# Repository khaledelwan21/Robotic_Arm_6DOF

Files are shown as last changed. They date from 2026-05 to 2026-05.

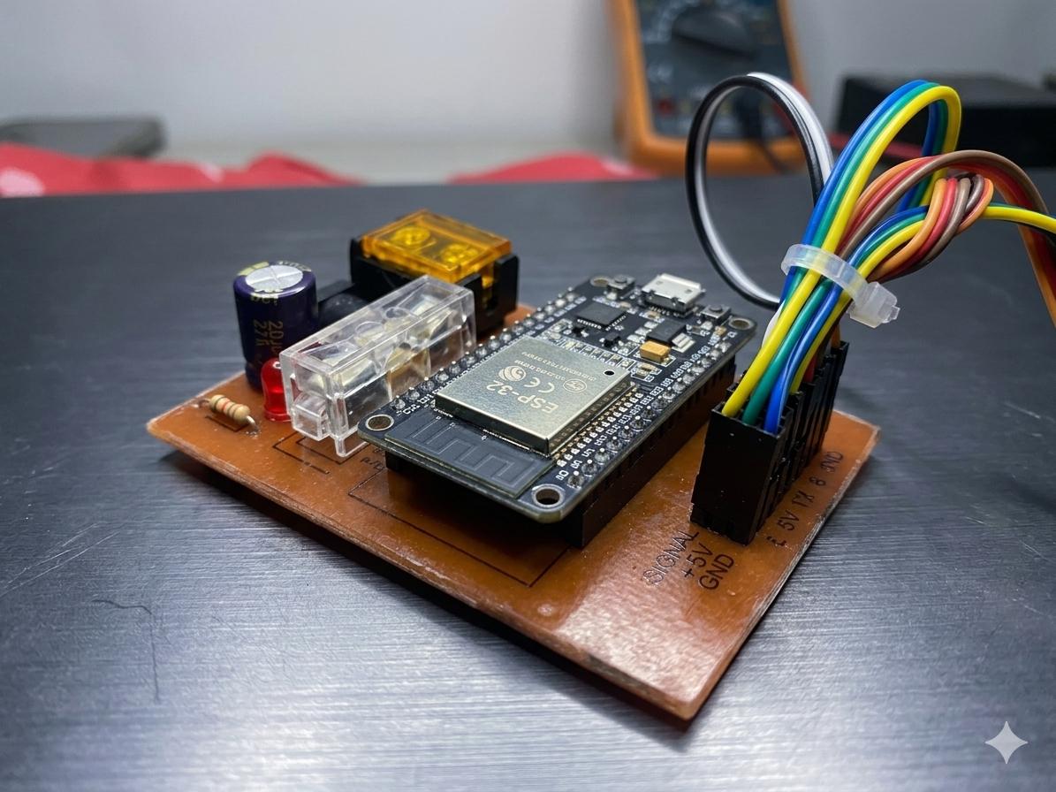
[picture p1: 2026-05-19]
PCB/PCB_VIEW.jpeg

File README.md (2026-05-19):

# 🦾 6-DOF Robotic Arm — Full Pipeline

> Trajectory Planning · Inverse Kinematics · ROS2 MoveIt2 · Real-Time Simulation · ESP32 Hardware Control







---

## 📌 Project Overview

A complete end-to-end 6 Degrees-of-Freedom robotic arm project developed at **Alexandria University, Faculty of Engineering**.

This repository covers the full development pipeline — from mechanical CAD design to physics simulation, trajectory planning, motion planning in ROS2, custom PCB hardware, and real-time teleoperation via PlayStation controller.

**Team:**
- Khaled Ahmed Elwan — ID: 8782
- Taha Ahmed Elaghoury — ID: 8745
- Marwan Mahmoud Ali Bakhit — ID: 9023

**Supervisor:** Dr. Sohair Rezeka

---

## 🗂️ Repository Structure

```
robotic-arm-6dof/
├── Matlab/                        # MATLAB Simscape simulation & trajectory planning
│   ├── ArmFK.slx                  # Main Simscape Multibody model
│   ├── myRoobot.m                 # Rigid body tree definition
│   ├── Arm_DataFile.m             # Link/joint data
│   ├── trajPlot.m                 # Trajectory visualization
│   └── FK_Plot.m                  # Forward kinematics plots
│
├── src/                           # ROS2 workspace packages
│   ├── robot_arm_description/     # URDF + STL meshes
│   ├── robot_arm_moveit_config/   # MoveIt2 configuration
│   └── robot_arm_control/         # Python trajectory scripts (MoveItPy)
│
├── pcb/                           # Custom PCB design (KiCad)
│
├── docs/
│   └── report.pdf                 # Full technical report
│
└── README.md
```

---

## 🔧 System Specifications

| Parameter | Value |
|---|---|
| Degrees of Freedom | 6 DOF |
| Joint Configuration | All Revolute |
| Joint Names | Shoulder · Elbow · Wrist · Rolling · Pitch · Gripper |
| Microcontroller | ESP32-WROOM DevKitC |
| Servo Motors | 5× MG996R + 1× SG90 |
| Simulation Engine | MATLAB Simscape Multibody |
| Motion Planner | OMPL RRTConnect (via MoveIt2) |
| IK Solver | KDL Kinematics Plugin |
| ROS Version | ROS2 Jazzy Jalisco |
| CAD Tool | SolidWorks 2023 |
| PCB Tool | KiCad |

---

## 📐 DH Parameters

| Joint | Link | a (mm) | d (mm) | α (°) | θ |
|---|---|---|---|---|---|
| 1 | Shoulder | 0 | 57 | 90 | θ1 |
| 2 | Elbow | 37.5 | 0 | 0 | θ2 |
| 3 | Wrist | 120 | 0 | 0 | θ3 |
| 4 | Rolling | 99.7 | 14.5 | 90 | θ4 |
| 5 | Pitch | 22.7 | 0 | -90 | θ5 |
| 6 | Gripper Base | 37.8 | 14.5 | 0 | θ6 |

---

## 🚀 Pipeline Overview

```
SolidWorks CAD
      ↓
MATLAB Simscape Multibody
      ↓  (Physics simulation + DH parameters)
Polynomial Trajectory Planner (5th-order)
      ↓  (Smooth waypoint interpolation)
IK Solver (MATLAB Robotics Toolbox)
      ↓  (Joint angles from Cartesian poses)
ESP32 Hardware Control (50Hz streaming via MATLAB)
      ↓
──────────────────────────────
SW2URDF Export (SolidWorks)
      ↓
ROS2 Jazzy + MoveIt2
      ↓  (OMPL RRTConnect + KDL IK)
RViz2 Real-Time Simulation
      ↓
PS Controller Teleoperation (Bluetooth)
```

---

## 1️⃣ MATLAB Simscape Simulation

### Features
- **5th-order Polynomial Trajectory** interpolation between Cartesian waypoints
- **IK Solver** maps end-effector poses → joint angles in real time
- **Forward Kinematics** verification confirms sub-mm accuracy
- **3D Trajectory Animation** — star shape, heart shape, custom paths
- **Workspace Analysis** — full reachable volume (~300mm radius sphere)

### Joint Limits

| Joint | Min | Max |
|---|-----|-----|
| Shoulder | -90° | +90° |
| Elbow | -90° | +90° |
| Wrist | -90° | +90° |
| Rolling | -90° | +90° |
| Pitch | -90° | +90° |
| Gripper | -90° | +90° |

### Run the Simulation

```matlab
% Open MATLAB R2024a
open('Matlab/ArmFK.slx')

% Run simulation
sim('ArmFK')

% Plot trajectory
run('Matlab/trajPlot.m')
```

---

## 2️⃣ ROS2 + MoveIt2 Setup

### Prerequisites

```bash
# Install ROS2 Jazzy
sudo apt install ros-jazzy-moveit
sudo apt install ros-jazzy-joint-state-publisher-gui
sudo apt install ros-jazzy-xacro
sudo apt install liburdfdom-tools
```

### Build

```bash
cd ros2_arm_ws
colcon build
source install/setup.bash
```

### Run

```bash
# Terminal 1 — Launch MoveIt2 + RViz2
ros2 launch robot_arm_moveit_config demo.launch.py

# Terminal 2 — Python trajectory control
ros2 launch robot_arm_control trajectory_planning.launch.py
```

### MoveIt2 Configuration
- **Planning Group:** `arm` (shoulder → elbow → wrist → rolling → pitch → follower-gear)
- **IK Solver:** KDL (`kdl_kinematics_plugin/KDLKinematicsPlugin`)
- **Motion Planner:** OMPL RRTConnect
- **Planning Time:** 5.0s | **Velocity Scaling:** 10%

---

## 3️⃣ PS Controller Teleoperation

Real-time Bluetooth teleoperation of the simulated arm via PlayStation controller:

```bash
# Install joy package
sudo apt install ros-jazzy-joy

# Connect PS controller via Bluetooth, then:
# Terminal 1 — Start MoveIt
ros2 launch robot_arm_moveit_config demo.launch.py

# Terminal 2 — Start joy node
ros2 run joy joy_node

# Terminal 3 — Start teleoperation
ros2 run robot_arm_control ps_teleop.py
```

---

## 4️⃣ ESP32 Hardware Control

### Angle Mapping Formula

```
servo_position = (joint_angle_deg + 90) / 180
```

| Joint Angle | Servo Position | Servo Angle |
|---|---|---|
| -90° | 0.0 | 0° |
| 0° | 0.5 | 90° |
| +90° | 1.0 | 180° |

### Pin Mapping

| Servo | ESP32 Pin | Joint |
|---|---|---|
| SERVO1 | D13 | Shoulder |
| SERVO2 | D12 | Elbow |
| SERVO3 | D14 | Wrist |
| SERVO4 | D27 | Rolling |
| SERVO5 | D26 | Pitch |
| SERVO6 | D25 | Gripper |

### Streaming from MATLAB

```matlab
% Connect to ESP32
a = arduino('COM9', 'ESP32');

% Stream joint angles at 50Hz
for i = 1:length(joint_angles)
    servo_pos = (joint_angles(i, :) + 90) / 180;
    writePosition(servo1, servo_pos(1));
    writePosition(servo2, servo_pos(2));
    % ... remaining joints
    pause(0.02); % 50Hz
end
```

---

## 5️⃣ Custom PCB

Designed in KiCad — clean ESP32 ↔ servo interface:

- 6-channel servo header connectors (SIGNAL · +5V · GND)
- 220µF electrolytic capacitor for servo power filtering
- Fuse protection on servo power rail
- Power jack for external 5V supply
- LED power indicator with 220Ω current-limiting resistor

---

## ✅ Results

| Objective | Status |
|---|---|
| SolidWorks 3D mechanical design | ✅ Complete |
| Simscape Multibody physics simulation | ✅ Complete |
| Polynomial trajectory planning | ✅ Complete |
| IK solver integration | ✅ Complete |
| 3D end-effector animation | ✅ Complete |
| Robot workspace visualization | ✅ Complete |
| ROS2 Jazzy URDF model | ✅ Complete |
| MoveIt2 real-time motion planning | ✅ Complete |
| PS controller teleoperation | ✅ Complete |
| Custom PCB design | ✅ Complete |
| ESP32 servo hardware control | ✅ Complete |

---

## 🔮 Future Work

- [ ] TRAC-IK upgrade for better singularity handling
- [ ] Gazebo physics simulation
- [ ] Camera integration for visual feedback
- [ ] Full hardware loop: PS Controller → ROS2 → ESP32 → Real Servos
- [ ] Pick & Place demo task

---

## 📚 References

1. MATLAB Robotics System Toolbox Documentation, MathWorks, R2024a
2. Simscape Multibody User Guide, MathWorks, R2024a
3. MoveIt2 Documentation — https://moveit.ros.org
4. ROS2 Jazzy Documentation — https://docs.ros.org/en/jazzy
5. Craig, J.J., *Introduction to Robotics: Mechanics and Control*, 3rd ed., Pearson, 2005
6. ESP32 Technical Reference Manual, Espressif Systems, 2024

**Faculty of Engineering — Alexandria University — 2025/2026**

---

<p align="center">
  <i>Built with ❤️ at Alexandria University</i>
</p>

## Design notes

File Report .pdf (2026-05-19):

## Faculty of Engineering Alexandria University

# 6-DOF Robotic Arm

## Trajectory Planning | Simulation | Hardware Control

## Submitted by:

Khaled Ahmed Elwan - ID: 8782 Taha Ahmed Elaghoury - ID: 8745 Marwan Mahmoud Ali Bakhit - ID: 9023

## Supervised by:

Dr. Sohair Rezeka

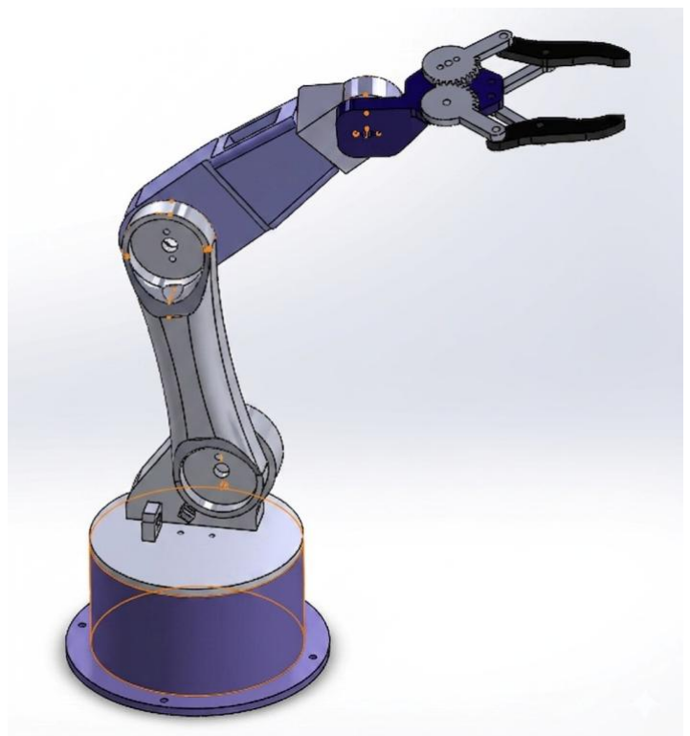
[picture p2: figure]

## 1. Introduction

This report presents the complete design, simulation, trajectory planning, and hardware implementation of a 6 Degrees-of-Freedom (6-DOF) robotic arm. The project integrates a multi-tool engineering workflow that covers the full development cycle, from mechanical CAD modeling and physics-based simulation to motion planning, custom electronics, and real-time servo actuation.

The project was developed by Khaled Ahmed Elwan (ID: 8782), Taha Ahmed Elaghoury (ID: 8745), and Marwan Mahmoud Ali Bakhit (ID: 9023), under the supervision of Dr. Sohair Rezeka at the Faculty of Engineering, Alexandria University.

The completed project stages are summarized as follows:

- Mechanical design of the complete robotic arm using SolidWorks
- Physics-based simulation using MATLAB Simscape Multibody
- Polynomial trajectory planning with six configurable Cartesian waypoints
- Inverse Kinematics (IK) solution using the MATLAB Robotics System Toolbox
- 3D end-effector path animation in MATLAB
- Robot workspace visualization and analysis
- Real-time motion planning and simulation using ROS2 Jazzy and MoveIt2 in RViz2
- Custom PCB design for servo motor interfacing and power distribution
- Hardware servo control using an ESP32-WROOM microcontroller

## 2. System Overview

The robotic arm was developed as a serial manipulator with revolute joints. The prototype includes five primary arm joints and an actuated gripper, providing the controlled motion required for positioning, orientation adjustment, and object handling. The system combines mechanical design, simulation, motion planning, and embedded control into a single integrated platform.

Parameter | Description
Degrees of Freedom | 6 DOF
Joint Configuration | Revolute joints
Joint Names | Shoulder, Elbow, Wrist, Rolling, Pitch, Gripper
Microcontroller | ESP32-WROOM DevKitC
Number of Servos | 5 active servos + 1 gripper servo
Servo Signal Pins | D13, D12, D14, D27, D26, D25
Control Software | MATLAB R2024a
Simulation Engine | Simscape Multibody
Motion Planner | Polynomial trajectory generation + IK solver
ROS Version | ROS2 Jazzy
Motion Planning Framework | MoveIt2
PCB Design Tool | KiCad
CAD Tool | SolidWorks

## 3. Mechanical Design (SolidWorks)

The complete robotic arm was designed from scratch using SolidWorks. Each component, including the links, joint housings, base, wrist elements, and gripper end-effector, was modeled individually and assembled with the required mechanical constraints to represent the intended joint motion.

The mechanical design workflow included the following steps:

- Individual part modeling for each link, joint housing, and gripper component
- Full assembly of the robotic arm with revolute joint constraints
- Definition of coordinate systems at the relevant joint and end-effector locations
- Gripper end-effector design for object grasping
- Export of the mechanical model for MATLAB Simscape Multibody simulation
- Export of the robot model for ROS2 and MoveIt2 integration
Figures 1 and 2 show the final SolidWorks assembly and the rendered CAD model of the complete robotic arm.

## 3.1 SolidWorks Modeling

In SolidWorks, the robotic arm assembly was constructed and adjusted to ensure accurate part positioning, joint alignment, and link connectivity. Coordinate systems were assigned to the individual components at the joint locations to define the relative motion between consecutive links and to support the subsequent export to Simscape Multibody.

Special attention was given to the end-effector coordinate system. This frame was placed within the end-effector sub-assembly rather than directly on individual gripper parts because assigning the frame to certain parts produced errors during the Simscape export process. Defining the frame at the sub-assembly level provided a more stable reference for the end-effector and improved the reliability of the exported model.

The mechanical assembly includes five main revolute joints responsible for the arm motion, in addition to the joints associated with the gripper mechanism. Each joint was designed to rotate about a defined axis. The base joint provides horizontal rotation of the arm, the shoulder and elbow joints provide vertical lifting and extension, the wrist joints provide end-effector orientation control, and the gripper enables object grasping and holding.

## 3.2 Fabrication

The robotic arm components were fabricated using fused-filament fabrication (FFF) on a Bambu P1S 3D printer. PLA was selected as the structural material, and a 50% infill density was applied to the printed parts.

PLA was selected because it offers high stiffness, low printing shrinkage, limited warping, and reliable dimensional stability compared with more flexible or difficult-to-print polymers. These properties make it suitable for functional robotic prototypes where accurate assembly, joint alignment, and repeatable motion are required. The 50% infill density was selected as an engineering compromise between rigidity, part mass, printing time, and material consumption. This infill level provides internal support and improves resistance to bending and torsional loads in the links and joint brackets, while avoiding unnecessary mass that would increase joint inertia and servo torque demand.

During the first fabrication trial, a print failure occurred, as indicated by the accumulation of loose extruded filament on the build plate. This failure mode is commonly associated with loss of first-layer adhesion, insufficient support, inaccurate bed leveling, or unstable bonding between the deposited filament and the build surface. Once the part detached or lost support, the nozzle continued extruding material without forming the intended geometry, resulting in a typical spaghetti-type FFF failure. The issue was addressed by checking bed leveling and adhesion, reviewing the slicing parameters, and verifying the required supports before reprinting the part.

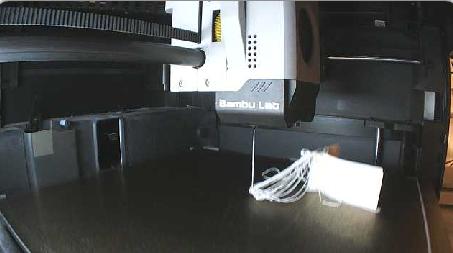
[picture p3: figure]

Initial FFF printing failure observed during the first fabrication trial.

## 3.3 Coordinate Axes and SMILINK Structure

During the SolidWorks-to-Simscape export process, the model generated a hierarchical Simscape Multibody Link structure, referred to as the SMILINK structure. This structure defines the relationships between the robot components, joints, and coordinate frames. It represents the connection sequence from the fixed world frame through the complete kinematic chain until the end-effector.

The exported model included several SMILINK frames, starting from the base reference and continuing through the arm links, wrist components, and end-effector. These frames define the relative position and orientation of each body with respect to the adjacent body. A clear coordinate hierarchy is essential for preserving the spatial relationship between the links and for enabling accurate forward and inverse kinematic calculations in MATLAB.

The gripper mechanism required additional connection points because it contains multiple moving components. These additional frames were necessary to preserve the coordinated motion of the gripper fingers during opening and closing while maintaining correct alignment with the end-effector reference frame.

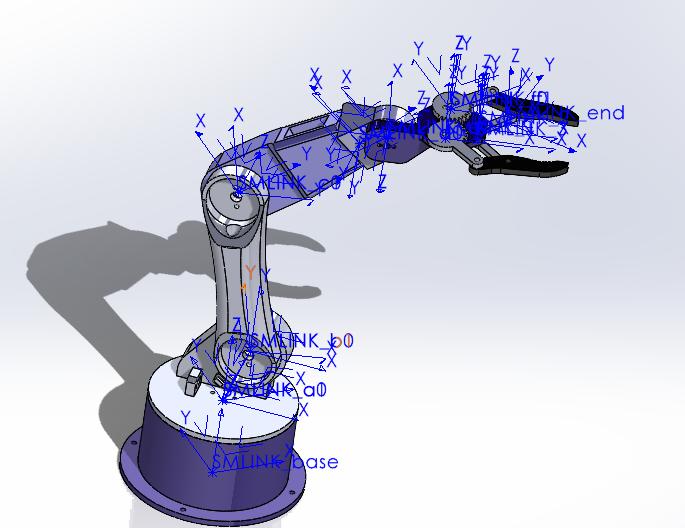
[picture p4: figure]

Figure 5: Simscape Multibody imported assembly showing link coordinate frames and end-effector reference frame.

## 3.4 Export to Simscape Multibody

The Simscape Multibody Link add-in was used to export the completed SolidWorks assembly into MATLAB Simscape Multibody. The export process converted the mechanical assembly, including its parts, joints, coordinate systems, and geometry files, into a Simscape-compatible model. The generated output included an XML file describing the multibody structure, STL geometry files for visualization, and a MATLAB script used to import and construct the model inside Simscape Multibody.

A major export issue was encountered when the complete assembly was exported with the servo motor models included. The presence of the servo bodies complicated the joint definitions and caused the revolute joints to become incorrectly interpreted or difficult for the software to identify. As a result, the generated model did not accurately represent the intended joint structure.

To resolve this issue, the servo motor models were removed from the SolidWorks assembly before export, and the joints were connected directly between the mechanical links. This simplified the multibody structure, reduced export errors, and produced a cleaner Simscape model suitable for simulation, trajectory planning, and control implementation.

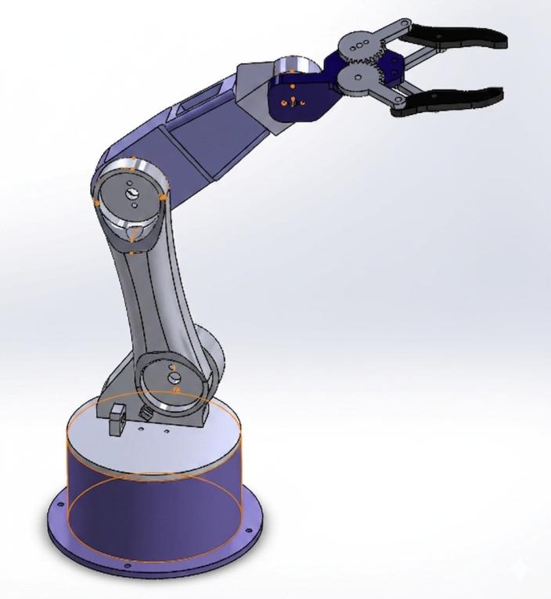
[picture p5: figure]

Figure 1: Final SolidWorks assembly of the 6-DOF robotic arm and gripper.

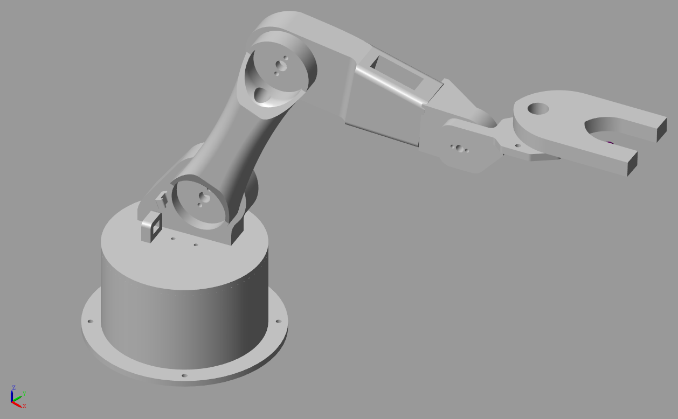
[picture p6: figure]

Figure 2: Rendered CAD model of the complete robotic arm assembly.

## 4. MATLAB Simscape Multibody Simulation

## 4.1 Model Architecture

The SolidWorks assembly was imported into MATLAB Simscape Multibody while preserving the main joint constraints, link geometries, and coordinate-frame relationships. The resulting model provides a physics-based representation of the robotic arm that can be connected directly to the trajectory-planning and control blocks in Simulink.

The Simulink model includes the following main blocks:

- Polynomial Trajectory block, which generates smooth joint-space or Cartesian trajectory profiles
- Coordinate Transformation Conversion block, which converts the trajectory output into SE(3) transformation matrices
- Inverse Kinematics (IK) Solver block, which computes the required joint angles from the desired Cartesian poses using the dof6 rigid-body-tree model
- myRobot Simscape block, which performs the physics-based simulation of the complete robotic arm
- Forward Kinematics (FK) verification block, which checks the end-effector position produced by the computed joint angles
- To Workspace blocks, which export the joint-angle data for post-processing and hardware control Figure 3 shows the MATLAB/Simulink pipeline used for trajectory generation, coordinate transformation, IK solving, Simscape simulation, and FK verification.

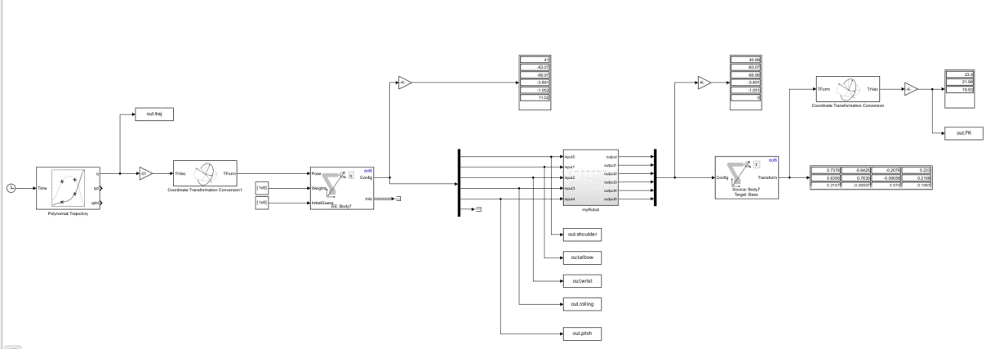
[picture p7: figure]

Figure 3: MATLAB/Simulink model architecture including polynomial trajectory generation, coordinate transformation, IK solving, Simscape simulation, and FK verification.

Figures 4 show the imported Simscape Multibody visualization

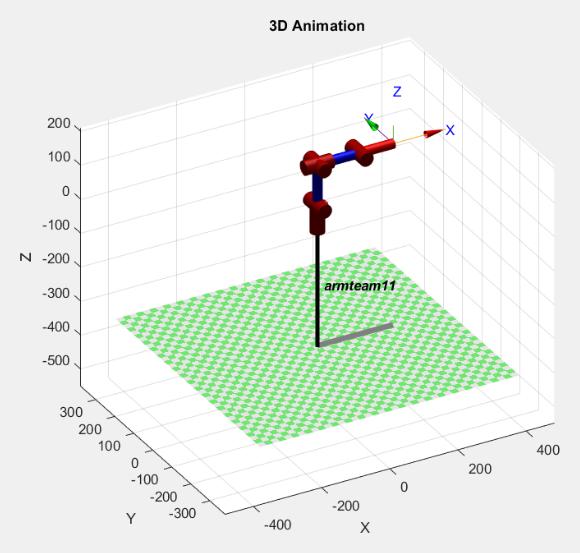
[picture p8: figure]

Figure 4: Simscape Multibody visualization of the robotic arm during 3D animation.

## 4.2 Trajectory Planning

Trajectory planning was implemented using fifth-order polynomial interpolation between user-defined Cartesian waypoints. The waypoints were defined as a 3 x N matrix representing the desired X, Y, and Z coordinates within the robot workspace. Zero boundary velocity conditions were applied at the start and end of each trajectory segment to produce smooth acceleration and deceleration behavior.

The IK solver operates on the dof6 rigid-body-tree model and computes the joint-angle vector [shoulder, elbow, wrist, rolling, pitch] required to place the end-effector at each point along the trajectory. Joint limits were considered during the IK computation to maintain physically feasible arm configurations throughout the motion.

## 4.3 Forward Kinematics Verification

The computed joint angles were passed through a Forward Kinematics block to verify the resulting end-effector pose. The FK output position was compared with the planned Cartesian trajectory to confirm that the IK solver produced valid joint configurations and that the simulated arm followed the intended path accurately.

## 5. Robot Workspace Analysis

The reachable workspace of the robotic arm was evaluated by uniformly sampling the permitted joint-angle ranges and calculating the corresponding end-effector positions in 3D Cartesian space. This method provides a practical visualization of the volume that the robot can reach while respecting the specified joint limits.

Joint | Minimum Angle | Maximum Angle
Shoulder | -90 degrees | +90 degrees
Elbow | -90 degrees | +90 degrees
Wrist | -90 degrees | +90 degrees
Rolling | -90 degrees | +90 degrees

Pitch | -90 degrees | +90 degrees
Gripper | -90 degrees | +90 degrees
The workspace analysis showed a near-spherical reachable volume with an approximate radius of 300 mm in the XY plane and a vertical Z-axis range extending from approximately -200 mm to +400 mm. A void region appears near the base due to mechanical self-collision constraints and the limited angular range of the shoulder joint.

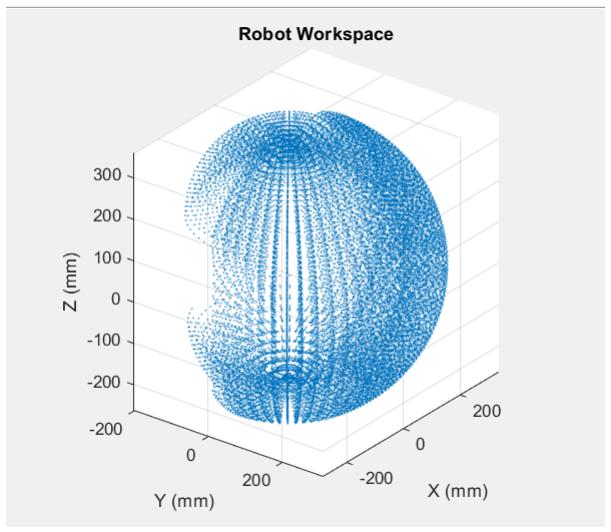
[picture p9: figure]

Figure 6: Computed robot workspace obtained by sampling the permitted joint-angle ranges.

## 6. 3D Trajectory Animation

A real-time 3D animation was developed in MATLAB to visualize the end-effector motion during simulation. The animation traces the Cartesian path of the end-effector while the robot executes the planned polynomial trajectory, allowing the motion behavior to be checked before hardware implementation.

Multiple trajectory shapes were tested to validate the trajectory-generation and IK pipeline:

- Star-shaped trajectory, used to test sharp directional changes while maintaining smooth polynomial interpolation
- Heart-shaped trajectory, used to evaluate continuous curved-path execution
- Custom waypoint paths, used to confirm general-purpose trajectory planning capability
The animation confirmed that the IK solver tracked the defined waypoints accurately and that polynomial interpolation produced continuous motion between consecutive trajectory points.

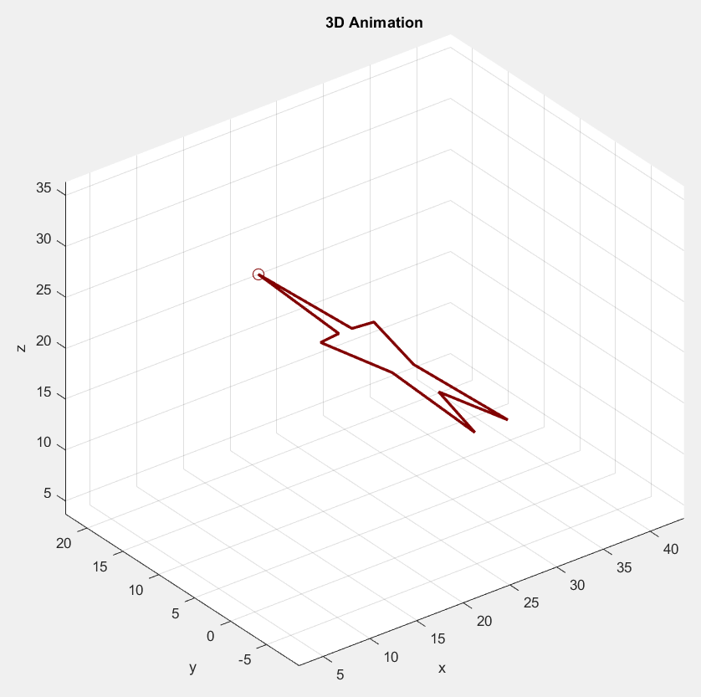
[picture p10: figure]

Figure 7: MATLAB 3D animation showing the generated end-effector trajectory path.

## 7. ROS2 Jazzy and MoveIt2 Integration

## 7.1 URDF Model

The robotic arm was configured as a URDF (Unified Robot Description Format) model to enable ROS2 compatibility. The URDF model defines the robot links, joint types, joint axes, inertial properties, visual geometry, and collision meshes derived from the SolidWorks design.

## 7.2 MoveIt2 Setup

MoveIt2 was configured using the MoveIt Setup Assistant. This process generated the SRDF (Semantic Robot Description Format), planning groups, joint limits, controller interfaces, and kinematics solver configuration. The KDL kinematics plugin was used to support inverse-kinematics calculations during motion planning.

## 7.3 Real-Time Simulation in RViz2

The robot was visualized and interactively controlled in RViz2 using the MoveIt2 MotionPlanning plugin. The joints panel was used to define target joint states, while MoveIt2 generated collision-free trajectories to reach the selected configurations in real time.

The following joint states were observed during one of the validation tests:

- Shoulder: -38 degrees
- Elbow: -43 degrees
- Wrist: -4 degrees
- Rolling: +11 degrees
- Pitch: 0 degrees
- Gripper: -24 degrees
The MoveIt2 simulation demonstrated successful real-time motion planning with correct joint tracking and smooth trajectory execution in the virtual environment.

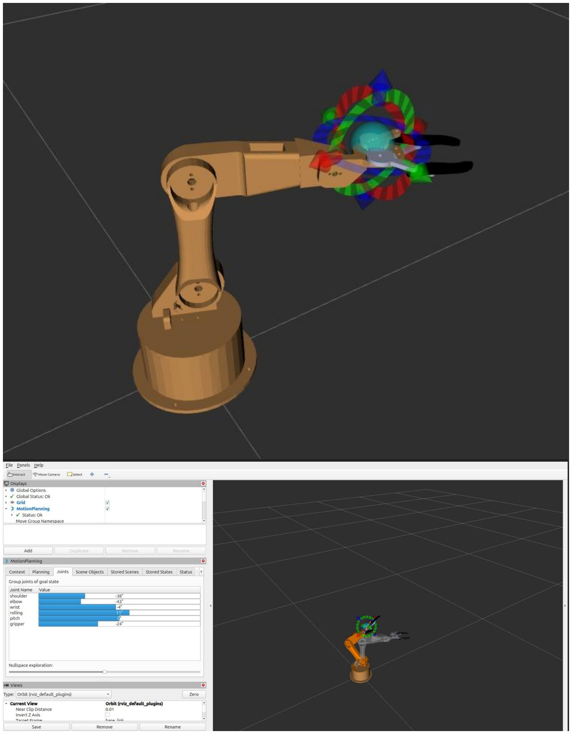
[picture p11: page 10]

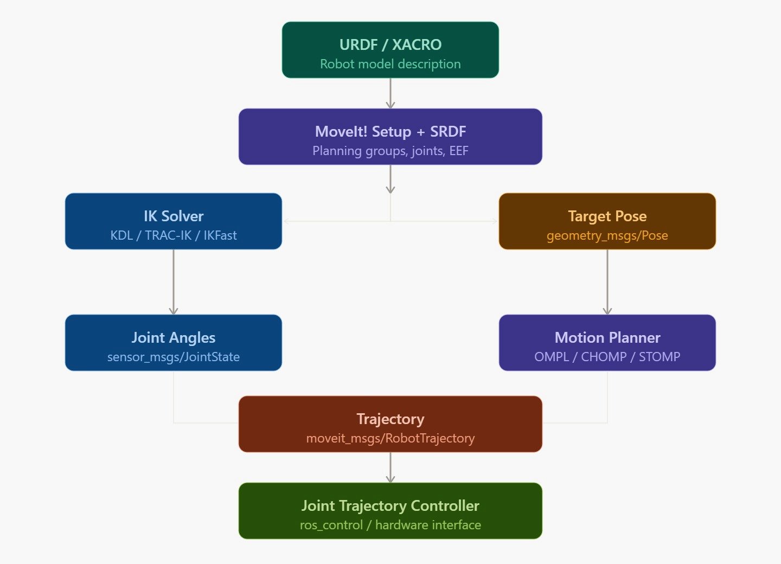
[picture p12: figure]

## 8. Custom PCB Control Board

## 8.1 Board Overview

A custom printed circuit board (PCB) was designed to provide a clean and reliable interface between the ESP32-WROOM microcontroller and the servo motors. The board was designed by Khaled Elwan at Alexandria University and was developed to simplify wiring, improve power distribution, and reduce connection errors during hardware testing.

The PCB design includes the following components and features:

- ESP32-WROOM-30 DevBoard used as the main microcontroller for PWM signal generation
- Six-channel servo header connectors providing signal, +5 V, and GND rails
- 220 uF electrolytic capacitor for servo power-rail filtering and voltage stabilization
- Fuse protection for the servo supply rail to reduce overcurrent risk
- Power-jack connector for external 5 V servo supply input
- LED power indicator with a 220-ohm current-limiting resistor
- Dedicated VCC and GND planes for improved power distribution and reduced wiring complexity

## 8.2 Servo Pin Mapping

Servo | ESP32 Pin | Function
SERVO1 | D13 | Shoulder joint
SERVO2 | D12 | Elbow joint
SERVO3 | D14 | Wrist joint
SERVO4 | D27 | Rolling joint

## 8.3 PCB Schematic

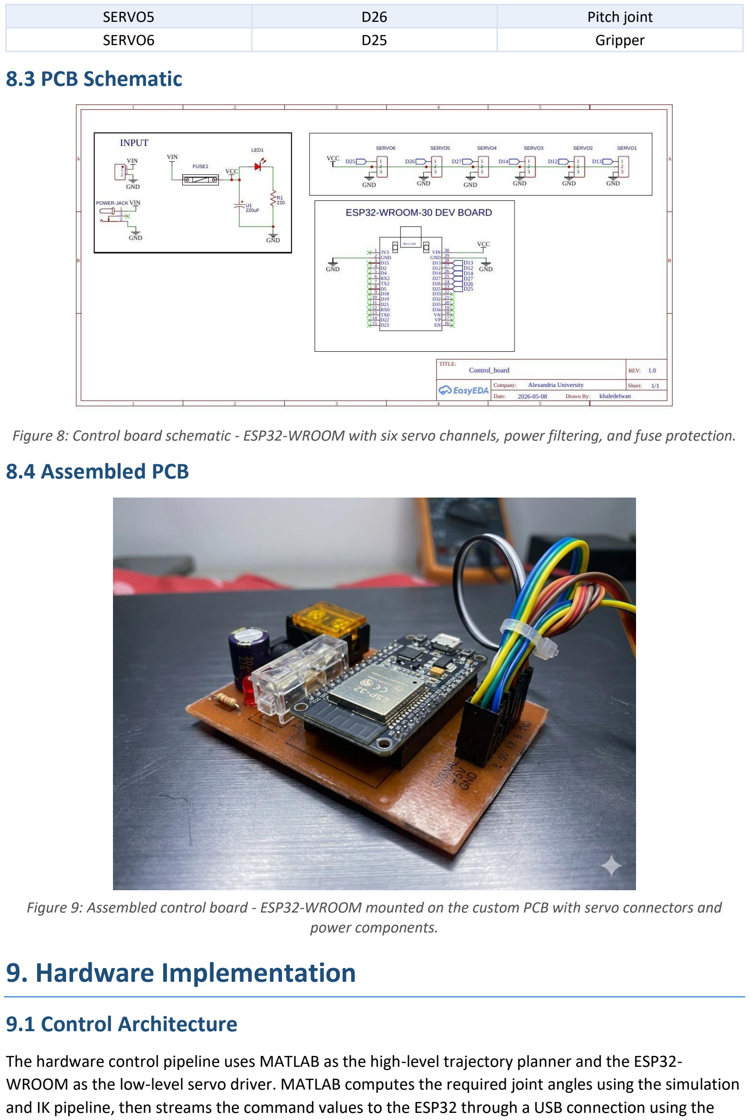
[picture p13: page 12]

SERVO5 | D26 | Pitch joint
SERVO6 | D25 | Gripper

Figure 8: Control board schematic - ESP32-WROOM with six servo channels, power filtering, and fuse protection.

## 8.4 Assembled PCB

Figure 9: Assembled control board - ESP32-WROOM mounted on the custom PCB with servo connectors and power components.

## 9. Hardware Implementation

## 9.1 Control Architecture

The hardware control pipeline uses MATLAB as the high-level trajectory planner and the ESP32-
WROOM as the low-level servo driver. MATLAB computes the required joint angles using the simulation and IK pipeline, then streams the command values to the ESP32 through a USB connection using the

MATLAB Support Package for Arduino Hardware. This approach eliminates the need to store the complete trajectory dataset on the microcontroller.

## 9.2 Control Pipeline

- MATLAB executes the Simscape simulation and IK solver to compute the joint-angle commands
- Joint angles are extracted in radians from the To Workspace blocks
- The angle values are converted from radians to degrees using rad2deg()
- The degree values are mapped from the mechanical range [-90 degrees, +90 degrees] to the normalized servo command range [0, 1]
- MATLAB streams the normalized command values to the ESP32 through the Arduino Support Package on COM9
- The ESP32 generates the servo PWM signals on pins D13, D12, D14, D27, and D26

## 9.3 Angle Mapping Formula

The servo writePosition() function accepts normalized command values from 0 to 1, where 0 corresponds to 0 degrees and 1 corresponds to 180 degrees. The joint angles obtained from the IK solver are therefore mapped using the following relation:

servo_position = (joint_angle_deg + 90) / 180

Joint Angle (deg) | Servo Position | Servo Angle
-90 degrees | 0.0 | 0 degrees
0 degrees | 0.5 | 90 degrees
+90 degrees | 1.0 | 180 degrees

## 9.4 RAM Optimization

A key implementation decision was to avoid deploying the full trajectory dataset to the ESP32 memory. The trajectory contained more than 4000 time steps, corresponding to approximately 157 kB of data. When combined with the runtime stack and required libraries, this memory demand was not suitable for direct storage and execution on the ESP32.

Instead, MATLAB streams one joint-angle vector per time step at a frequency of 50 Hz, corresponding to a 20 ms update interval. This approach keeps the ESP32 memory footprint low and allows the microcontroller to operate as a real-time PWM signal generator while MATLAB performs the computationally intensive trajectory and kinematics calculations.

## 10. Results and Discussion

The integrated system successfully demonstrated an end-to-end robotic arm development pipeline. The mechanical design was imported into Simscape, simulated using MATLAB and Simulink, connected to trajectory planning and IK computation, visualized through workspace and 3D animation tools, and finally linked to servo control through the ESP32-based hardware platform.

The main project objectives and their completion status are summarized below:

Objective | Status
SolidWorks 3D mechanical design | Completed
Simscape Multibody physics simulation | Completed
Polynomial trajectory planning | Completed
Inverse Kinematics (IK) solver integration | Completed

3D end-effector path animation (star and heart trajectories) | Completed
Robot workspace visualization | Completed
ROS2 Jazzy URDF model | Completed
MoveIt2 real-time motion planning | Completed
Custom PCB control board design | Completed
ESP32 servo hardware control | Completed

## 11. Conclusion

This project successfully delivered a complete robotic arm system that integrates mechanical design, physics-based simulation, trajectory planning, motion planning, custom PCB hardware, and real-time servo control. The combined workflow involving SolidWorks, MATLAB Simscape Multibody, ROS2 MoveIt2, and ESP32 demonstrates a structured and professional robotics development approach.
The polynomial trajectory planner provides smooth and configurable motion paths between Cartesian waypoints, while the IK solver calculates the corresponding joint angles required to execute the motion. The Simscape model enables physics-based validation of the robotic arm, and the MoveIt2 integration supports advanced motion planning with collision-aware trajectory generation. The custom PCB provides an organized and reliable hardware interface for controlling the servo motors.
Future enhancements may include integrating a camera module for visual feedback, implementing Gazebo-based physics simulation for pre-deployment testing, and adding a PlayStation controller interface for intuitive teleoperation and manual control.

## References

[1] MATLAB Robotics System Toolbox Documentation, MathWorks, R2024a.
[2] Simscape Multibody User Guide, MathWorks, R2024a.
[3] MoveIt2 Documentation, Open Robotics, 2024. https://moveit.ros.org
[4] ROS2 Jazzy Documentation, Open Robotics, 2024. https://docs.ros.org/en/jazzy
[5] J. J. Craig, Introduction to Robotics: Mechanics and Control, 3rd ed., Pearson, 2005.
[6] ESP32 Technical Reference Manual, Espressif Systems, 2024.
[7] SolidWorks Documentation, Dassault Systemes, 2024.

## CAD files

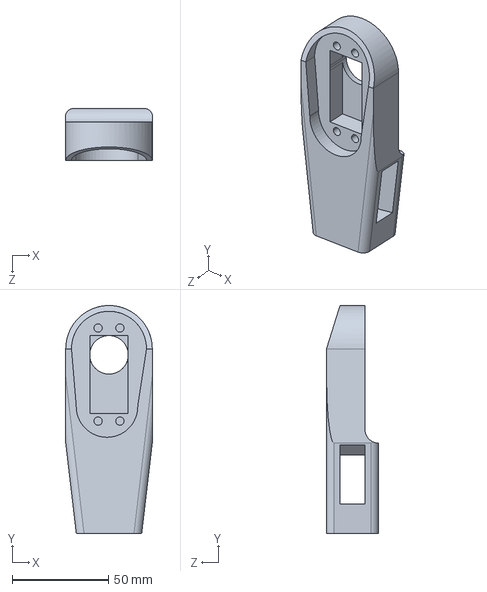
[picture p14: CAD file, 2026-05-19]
MaTlab/Arm2_Default_sldprt.STEP
45.0 x 118.5 x 27.0 mm

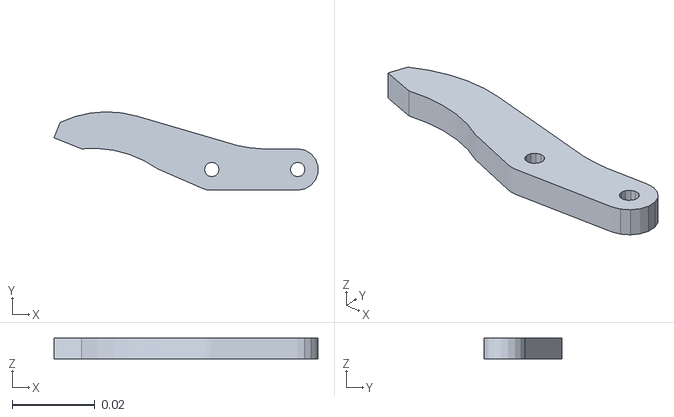
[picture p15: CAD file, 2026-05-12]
MaTlab/URDF/URDF/meshes/hand2.STL
0.0638 x 0.0189 x 0.005

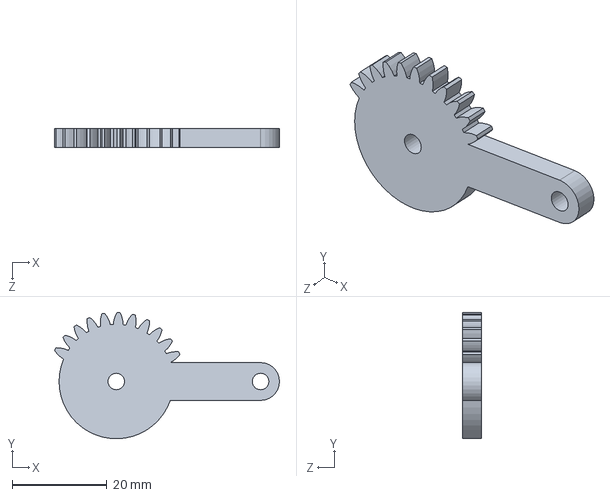
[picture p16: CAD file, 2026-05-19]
SoildWorks/Gear_1.SLDPRT
47.6 x 26.7 x 4.00 mm

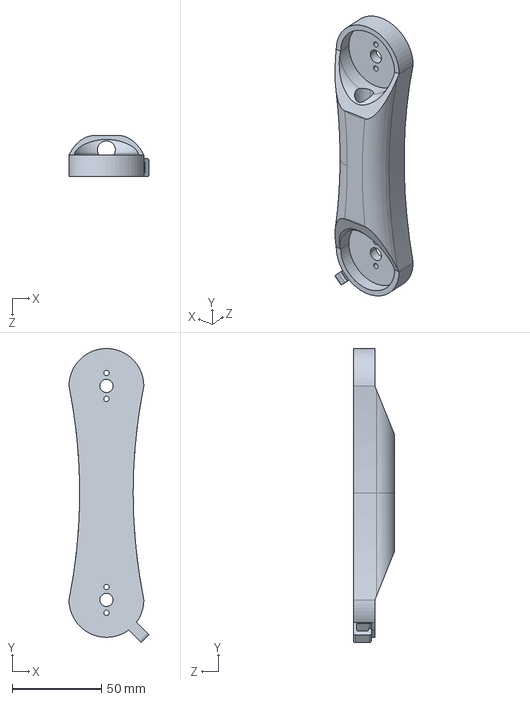
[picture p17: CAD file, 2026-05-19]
MaTlab/Arm1_Default_sldprt.STEP
44.9 x 164.9 x 23.0 mm

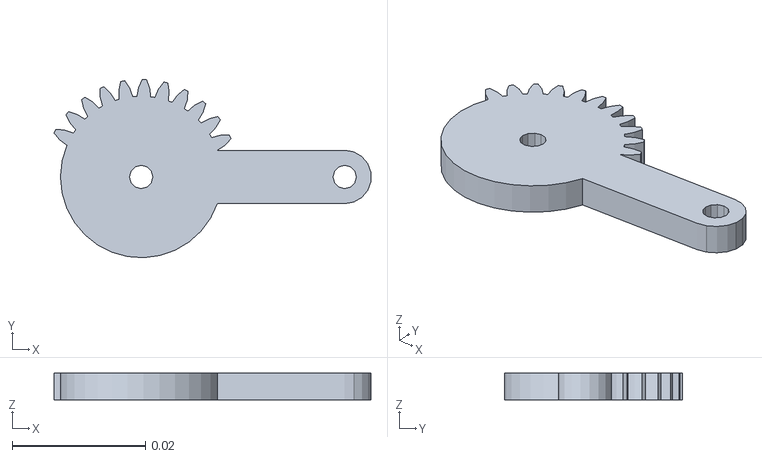
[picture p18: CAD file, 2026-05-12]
MaTlab/URDF/URDF/meshes/follower-gear.STL
0.0475 x 0.0267 x 0.004

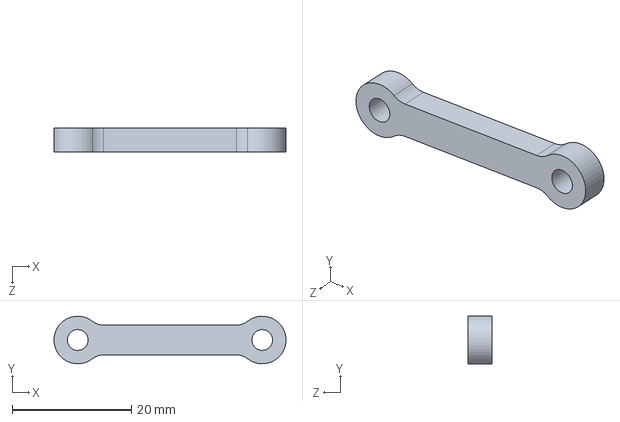
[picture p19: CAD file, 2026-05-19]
SoildWorks/Link2.SLDPRT
39.0 x 7.99 x 4.00 mm

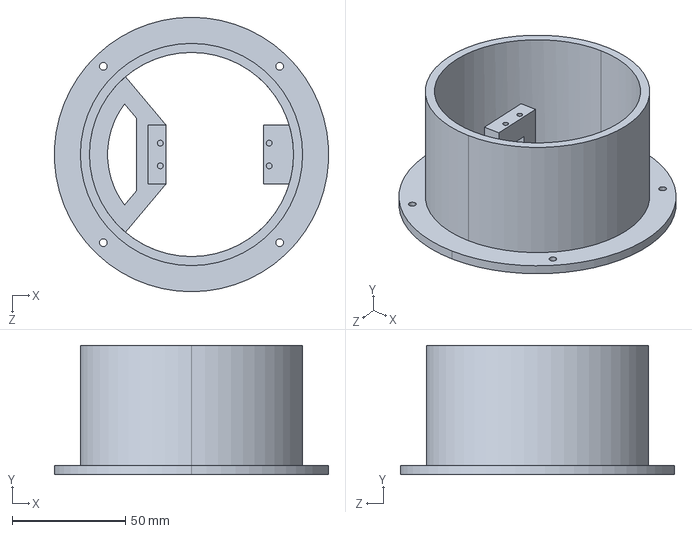
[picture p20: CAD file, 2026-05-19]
MaTlab/BaseT_Default_sldprt.STEP
120.8 x 57.0 x 121.0 mm

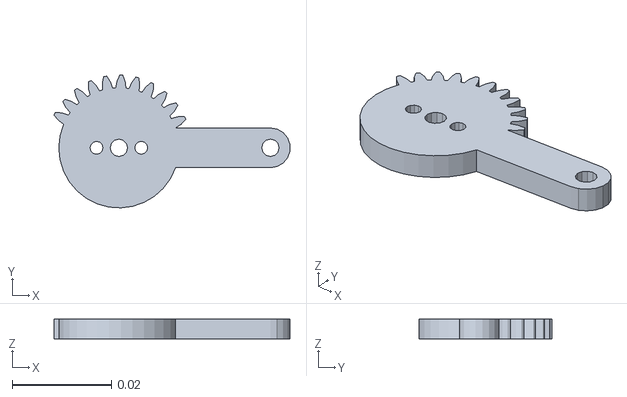
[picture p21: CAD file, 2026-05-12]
MaTlab/URDF/URDF/meshes/gripper.STL
0.0475 x 0.0267 x 0.004

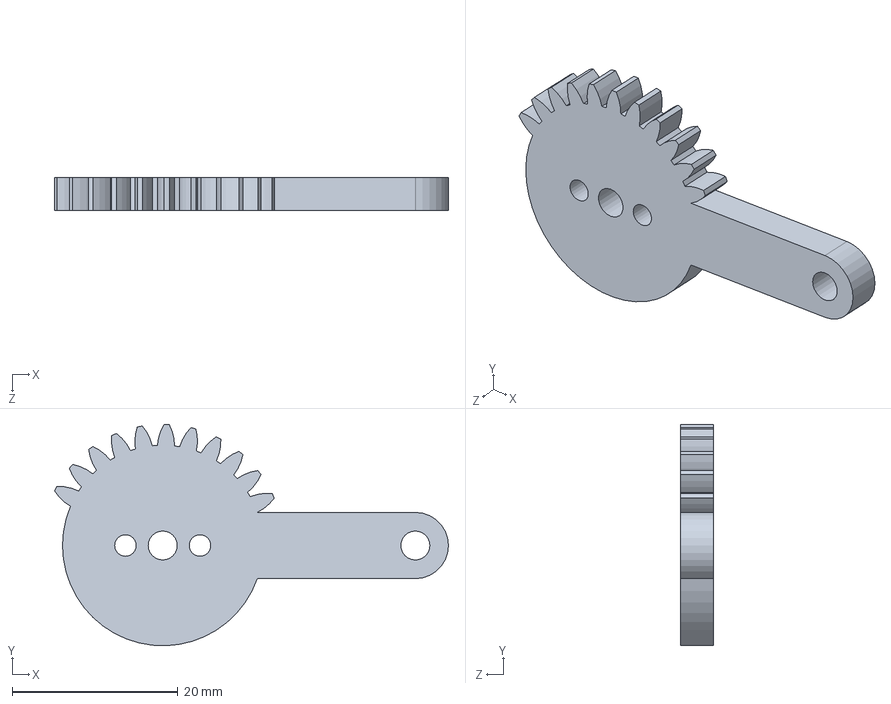
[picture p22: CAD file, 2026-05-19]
SoildWorks/Gear_2.SLDPRT
47.6 x 26.7 x 4.00 mm

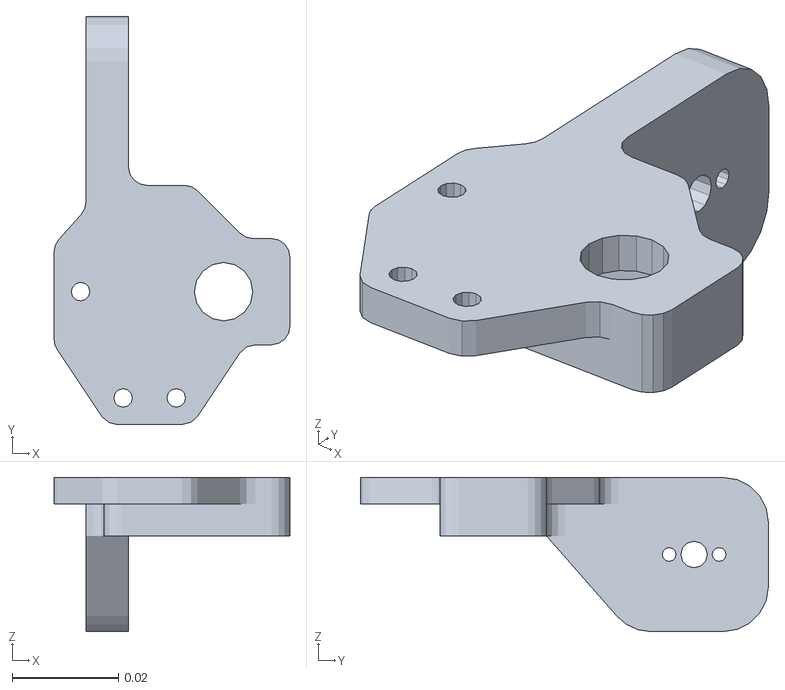
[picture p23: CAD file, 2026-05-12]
MaTlab/URDF/URDF/meshes/pitch.STL
0.0444 x 0.0768 x 0.029

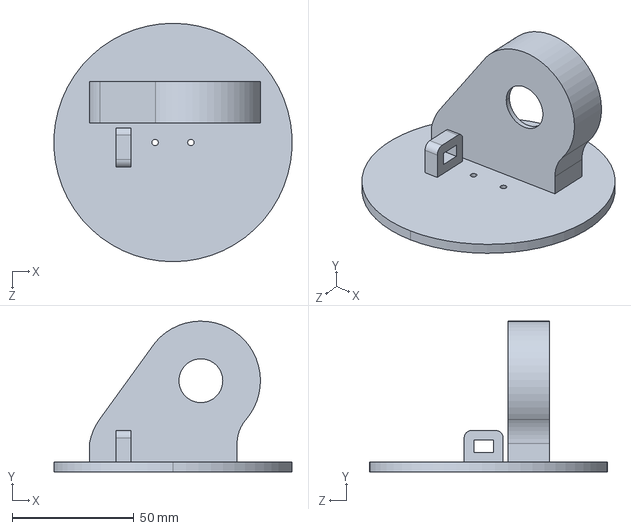
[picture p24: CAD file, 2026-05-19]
MaTlab/WaistT_Default_sldprt.STEP
97.9 x 62.0 x 98.0 mm

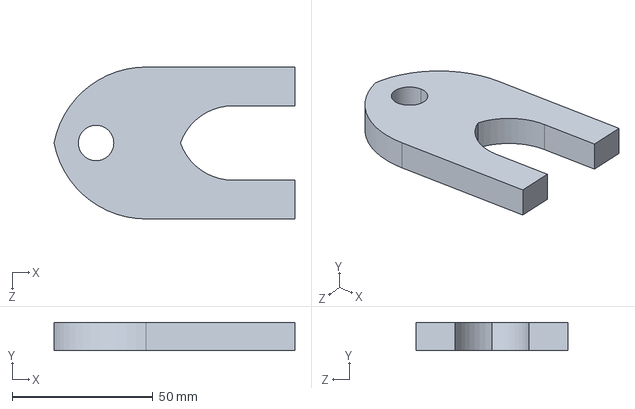
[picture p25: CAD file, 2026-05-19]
MaTlab/gripper_Default_sldprt.STEP
85.6 x 10.0 x 53.9 mm

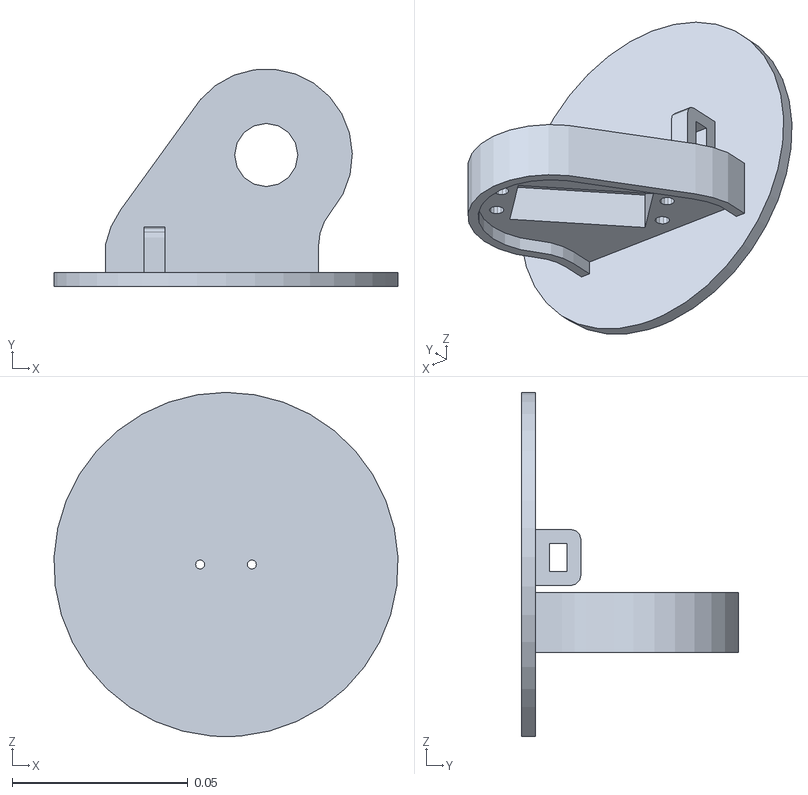
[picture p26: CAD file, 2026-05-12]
MaTlab/URDF/URDF/meshes/shoulder.STL
0.0979 x 0.0619 x 0.098

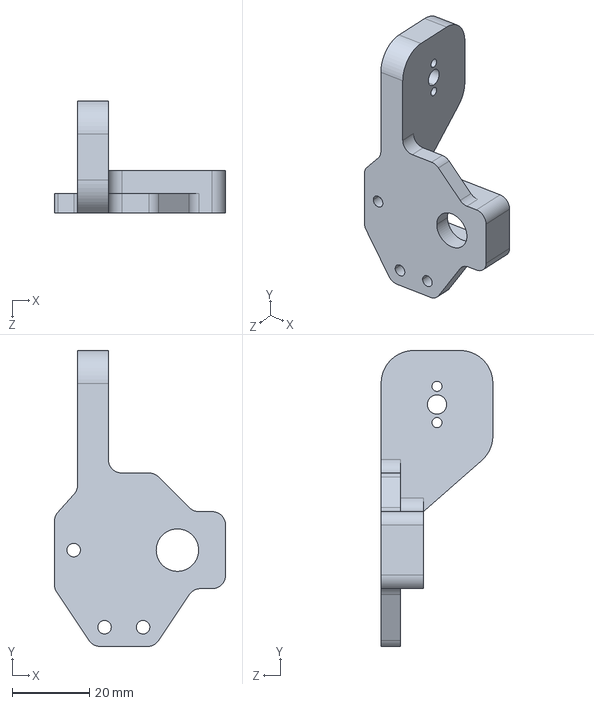
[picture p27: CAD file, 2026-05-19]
MaTlab/Gripper _base_Default_sldprt.STEP
44.4 x 76.8 x 29.0 mm

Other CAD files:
SoildWorks/Arm.SLDASM
SoildWorks/Arm2.SLDPRT
SoildWorks/WaistT.SLDPRT
MaTlab/URDF/URDF/meshes/elbow.STL
MaTlab/L_Default_sldprt.STEP
MaTlab/URDF/URDF/meshes/base_link.STL
MaTlab/URDF/URDF/meshes/hand1.STL
MaTlab/URDF/URDF/meshes/link1.STL
MaTlab/URDF/URDF/meshes/link2.STL
MaTlab/URDF/URDF/meshes/rest.STL
MaTlab/URDF/URDF/meshes/rolling.STL
SoildWorks/Arm1.SLDPRT
SoildWorks/BaseT.SLDPRT
SoildWorks/Gripper _base.SLDPRT
SoildWorks/Gripper1.SLDPRT
SoildWorks/Gripper2.SLDPRT
SoildWorks/L.SLDPRT
SoildWorks/Link1.SLDPRT

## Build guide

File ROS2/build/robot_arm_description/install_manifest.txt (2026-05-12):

/home/khaled-ahmed-elwan/ros2_arm_ws/install/robot_arm_description/share/ament_index/resource_index/package_run_dependencies/robot_arm_description
/home/khaled-ahmed-elwan/ros2_arm_ws/install/robot_arm_description/share/ament_index/resource_index/parent_prefix_path/robot_arm_description
/home/khaled-ahmed-elwan/ros2_arm_ws/install/robot_arm_description/share/robot_arm_description/environment/ament_prefix_path.sh
/home/khaled-ahmed-elwan/ros2_arm_ws/install/robot_arm_description/share/robot_arm_description/environment/ament_prefix_path.dsv
/home/khaled-ahmed-elwan/ros2_arm_ws/install/robot_arm_description/share/robot_arm_description/environment/path.sh
/home/khaled-ahmed-elwan/ros2_arm_ws/install/robot_arm_description/share/robot_arm_description/environment/path.dsv
/home/khaled-ahmed-elwan/ros2_arm_ws/install/robot_arm_description/share/robot_arm_description/local_setup.bash
/home/khaled-ahmed-elwan/ros2_arm_ws/install/robot_arm_description/share/robot_arm_description/local_setup.sh
/home/khaled-ahmed-elwan/ros2_arm_ws/install/robot_arm_description/share/robot_arm_description/local_setup.zsh
/home/khaled-ahmed-elwan/ros2_arm_ws/install/robot_arm_description/share/robot_arm_description/local_setup.dsv
/home/khaled-ahmed-elwan/ros2_arm_ws/install/robot_arm_description/share/robot_arm_description/package.dsv
/home/khaled-ahmed-elwan/ros2_arm_ws/install/robot_arm_description/share/ament_index/resource_index/packages/robot_arm_description
/home/khaled-ahmed-elwan/ros2_arm_ws/install/robot_arm_description/share/robot_arm_description/cmake/robot_arm_descriptionConfig.cmake
/home/khaled-ahmed-elwan/ros2_arm_ws/install/robot_arm_description/share/robot_arm_description/cmake/robot_arm_descriptionConfig-version.cmake
/home/khaled-ahmed-elwan/ros2_arm_ws/install/robot_arm_description/share/robot_arm_description/package.xml
/home/khaled-ahmed-elwan/ros2_arm_ws/install/robot_arm_description/share/robot_arm_description/urdf/arm.urdf
/home/khaled-ahmed-elwan/ros2_arm_ws/install/robot_arm_description/share/robot_arm_description/meshes/hand2.STL
/home/khaled-ahmed-elwan/ros2_arm_ws/install/robot_arm_description/share/robot_arm_description/meshes/follower-gear.STL
/home/khaled-ahmed-elwan/ros2_arm_ws/install/robot_arm_description/share/robot_arm_description/meshes/gripper.STL
/home/khaled-ahmed-elwan/ros2_arm_ws/install/robot_arm_description/share/robot_arm_description/meshes/shoulder.STL
/home/khaled-ahmed-elwan/ros2_arm_ws/install/robot_arm_description/share/robot_arm_description/meshes/hand1.STL
/home/khaled-ahmed-elwan/ros2_arm_ws/install/robot_arm_description/share/robot_arm_description/meshes/pitch.STL
/home/khaled-ahmed-elwan/ros2_arm_ws/install/robot_arm_description/share/robot_arm_description/meshes/rest.STL
/home/khaled-ahmed-elwan/ros2_arm_ws/install/robot_arm_description/share/robot_arm_description/meshes/rolling.STL
/home/khaled-ahmed-elwan/ros2_arm_ws/install/robot_arm_description/share/robot_arm_description/meshes/link2.STL
/home/khaled-ahmed-elwan/ros2_arm_ws/install/robot_arm_description/share/robot_arm_description/meshes/base_link.STL
/home/khaled-ahmed-elwan/ros2_arm_ws/install/robot_arm_description/share/robot_arm_description/meshes/link1.STL
/home/khaled-ahmed-elwan/ros2_arm_ws/install/robot_arm_description/share/robot_arm_description/meshes/elbow.STL

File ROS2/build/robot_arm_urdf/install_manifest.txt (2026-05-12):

/home/khaled-ahmed-elwan/ros2_arm_ws/install/robot_arm_urdf/share/robot_arm_urdf/meshes/hand2.STL
/home/khaled-ahmed-elwan/ros2_arm_ws/install/robot_arm_urdf/share/robot_arm_urdf/meshes/follower-gear.STL
/home/khaled-ahmed-elwan/ros2_arm_ws/install/robot_arm_urdf/share/robot_arm_urdf/meshes/gripper.STL
/home/khaled-ahmed-elwan/ros2_arm_ws/install/robot_arm_urdf/share/robot_arm_urdf/meshes/shoulder.STL
/home/khaled-ahmed-elwan/ros2_arm_ws/install/robot_arm_urdf/share/robot_arm_urdf/meshes/hand1.STL
/home/khaled-ahmed-elwan/ros2_arm_ws/install/robot_arm_urdf/share/robot_arm_urdf/meshes/pitch.STL
/home/khaled-ahmed-elwan/ros2_arm_ws/install/robot_arm_urdf/share/robot_arm_urdf/meshes/rest.STL
/home/khaled-ahmed-elwan/ros2_arm_ws/install/robot_arm_urdf/share/robot_arm_urdf/meshes/rolling.STL
/home/khaled-ahmed-elwan/ros2_arm_ws/install/robot_arm_urdf/share/robot_arm_urdf/meshes/link2.STL
/home/khaled-ahmed-elwan/ros2_arm_ws/install/robot_arm_urdf/share/robot_arm_urdf/meshes/base_link.STL
/home/khaled-ahmed-elwan/ros2_arm_ws/install/robot_arm_urdf/share/robot_arm_urdf/meshes/link1.STL
/home/khaled-ahmed-elwan/ros2_arm_ws/install/robot_arm_urdf/share/robot_arm_urdf/meshes/elbow.STL
/home/khaled-ahmed-elwan/ros2_arm_ws/install/robot_arm_urdf/share/robot_arm_urdf/urdf/robot_arm.urdf
/home/khaled-ahmed-elwan/ros2_arm_ws/install/robot_arm_urdf/share/robot_arm_urdf/urdf/package.xml
/home/khaled-ahmed-elwan/ros2_arm_ws/install/robot_arm_urdf/share/robot_arm_urdf/urdf/URDF.csv
/home/khaled-ahmed-elwan/ros2_arm_ws/install/robot_arm_urdf/share/robot_arm_urdf/urdf/CMakeLists.txt
/home/khaled-ahmed-elwan/ros2_arm_ws/install/robot_arm_urdf/share/robot_arm_urdf/urdf/launch/gazebo.launch
/home/khaled-ahmed-elwan/ros2_arm_ws/install/robot_arm_urdf/share/robot_arm_urdf/urdf/launch/display.launch
/home/khaled-ahmed-elwan/ros2_arm_ws/install/robot_arm_urdf/share/robot_arm_urdf/urdf/export.log
/home/khaled-ahmed-elwan/ros2_arm_ws/install/robot_arm_urdf/share/robot_arm_urdf/urdf/config/joint_names_URDF.yaml
/home/khaled-ahmed-elwan/ros2_arm_ws/install/robot_arm_urdf/share/robot_arm_urdf/urdf/meshes/hand2.STL
/home/khaled-ahmed-elwan/ros2_arm_ws/install/robot_arm_urdf/share/robot_arm_urdf/urdf/meshes/follower-gear.STL
/home/khaled-ahmed-elwan/ros2_arm_ws/install/robot_arm_urdf/share/robot_arm_urdf/urdf/meshes/gripper.STL
/home/khaled-ahmed-elwan/ros2_arm_ws/install/robot_arm_urdf/share/robot_arm_urdf/urdf/meshes/shoulder.STL
/home/khaled-ahmed-elwan/ros2_arm_ws/install/robot_arm_urdf/share/robot_arm_urdf/urdf/meshes/hand1.STL
/home/khaled-ahmed-elwan/ros2_arm_ws/install/robot_arm_urdf/share/robot_arm_urdf/urdf/meshes/pitch.STL
/home/khaled-ahmed-elwan/ros2_arm_ws/install/robot_arm_urdf/share/robot_arm_urdf/urdf/meshes/rest.STL
/home/khaled-ahmed-elwan/ros2_arm_ws/install/robot_arm_urdf/share/robot_arm_urdf/urdf/meshes/rolling.STL
/home/khaled-ahmed-elwan/ros2_arm_ws/install/robot_arm_urdf/share/robot_arm_urdf/urdf/meshes/link2.STL
/home/khaled-ahmed-elwan/ros2_arm_ws/install/robot_arm_urdf/share/robot_arm_urdf/urdf/meshes/base_link.STL
/home/khaled-ahmed-elwan/ros2_arm_ws/install/robot_arm_urdf/share/robot_arm_urdf/urdf/meshes/link1.STL
/home/khaled-ahmed-elwan/ros2_arm_ws/install/robot_arm_urdf/share/robot_arm_urdf/urdf/meshes/elbow.STL
/home/khaled-ahmed-elwan/ros2_arm_ws/install/robot_arm_urdf/share/robot_arm_urdf/urdf/urdf/URDF.csv
/home/khaled-ahmed-elwan/ros2_arm_ws/install/robot_arm_urdf/share/robot_arm_urdf/urdf/urdf/URDF.urdf
/home/khaled-ahmed-elwan/ros2_arm_ws/install/robot_arm_urdf/share/robot_arm_urdf/launch/display.launch.py
/home/khaled-ahmed-elwan/ros2_arm_ws/install/robot_arm_urdf/share/ament_index/resource_index/package_run_dependencies/robot_arm_urdf
/home/khaled-ahmed-elwan/ros2_arm_ws/install/robot_arm_urdf/share/ament_index/resource_index/parent_prefix_path/robot_arm_urdf
/home/khaled-ahmed-elwan/ros2_arm_ws/install/robot_arm_urdf/share/robot_arm_urdf/environment/ament_prefix_path.sh
/home/khaled-ahmed-elwan/ros2_arm_ws/install/robot_arm_urdf/share/robot_arm_urdf/environment/ament_prefix_path.dsv
/home/khaled-ahmed-elwan/ros2_arm_ws/install/robot_arm_urdf/share/robot_arm_urdf/environment/path.sh
/home/khaled-ahmed-elwan/ros2_arm_ws/install/robot_arm_urdf/share/robot_arm_urdf/environment/path.dsv
/home/khaled-ahmed-elwan/ros2_arm_ws/install/robot_arm_urdf/share/robot_arm_urdf/local_setup.bash
/home/khaled-ahmed-elwan/ros2_arm_ws/install/robot_arm_urdf/share/robot_arm_urdf/local_setup.sh
/home/khaled-ahmed-elwan/ros2_arm_ws/install/robot_arm_urdf/share/robot_arm_urdf/local_setup.zsh
/home/khaled-ahmed-elwan/ros2_arm_ws/install/robot_arm_urdf/share/robot_arm_urdf/local_setup.dsv
/home/khaled-ahmed-elwan/ros2_arm_ws/install/robot_arm_urdf/share/robot_arm_urdf/package.dsv
/home/khaled-ahmed-elwan/ros2_arm_ws/install/robot_arm_urdf/share/ament_index/resource_index/packages/robot_arm_urdf
/home/khaled-ahmed-elwan/ros2_arm_ws/install/robot_arm_urdf/share/robot_arm_urdf/cmake/robot_arm_urdfConfig.cmake
/home/khaled-ahmed-elwan/ros2_arm_ws/install/robot_arm_urdf/share/robot_arm_urdf/cmake/robot_arm_urdfConfig-version.cmake
/home/khaled-ahmed-elwan/ros2_arm_ws/install/robot_arm_urdf/share/robot_arm_urdf/package.xml

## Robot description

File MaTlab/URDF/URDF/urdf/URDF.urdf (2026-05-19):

<?xml version="1.0" encoding="utf-8"?>
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
<robot name="URDF">
  <link name="base_link">
    <inertial>
      <origin xyz="-0.000884042011461788 -2.68522483504429E-07 0.0227074694415587" rpy="0 0 0" />
      <mass value="0.120126872366986" />
      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
    </inertial>
    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
  </link>
  <link name="shoulder">
    <inertial>
      <origin xyz="0.00137847335109012 0.0156184793547242 -0.00728640518089488" rpy="0 0 0" />
      <mass value="0.0771455988127503" />
      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
    </inertial>
    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
  </link>
  <joint name="shoulder" type="revolute">
    <origin xyz="0 0 0.057" rpy="1.5708 0 1.1754" />
    <parent link="base_link" />
    <child link="shoulder" />
    <axis xyz="0 1 0" />
    <limit lower="-1.5707" upper="1.5707" effort="3" velocity="3" />
  </joint>
  <link name="elbow">
    <inertial>
      <origin xyz="8.33915294182726E-05 0.0596540948617726 -0.000712431979583381" rpy="0 0 0" />
      <mass value="0.0888458236237444" />
      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
    </inertial>
    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
  </link>
  <joint name="elbow" type="revolute">
    <origin xyz="0.011458 0.037477 0" rpy="3.1416 0 3.0995" />
    <parent link="shoulder" />
    <child link="elbow" />
    <axis xyz="0 0 1" />
    <limit lower="-1.5707" upper="1.5707" effort="3" velocity="3" />
  </joint>
  <link name="rest">
    <inertial>
      <origin xyz="-0.000117177420813491 -0.0408715532218013 0.015152337193664" rpy="0 0 0" />
      <mass value="0.0841589044535185" />
      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
    </inertial>
    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
  </link>
  <joint name="wrist" type="revolute">
    <origin xyz="0 0.12 0" rpy="0 0 -1.6128" />
    <parent link="elbow" />
    <child link="rest" />
    <axis xyz="0 0 1" />
    <limit lower="-1.5707" upper="1.5707" effort="3" velocity="3" />
  </joint>
  <link name="rolling">
    <inertial>
      <origin xyz="0.00502760760291043 0.0109445217827496 -0.00535441479370665" rpy="0 0 0" />
      <mass value="0.0205470147246711" />
      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
    </inertial>
    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
  </link>
  <joint name="rolling" type="revolute">
    <origin xyz="0.0055 -0.099677 0.0145" rpy="0 0 -3.1416" />
    <parent link="rest" />
    <child link="rolling" />
    <axis xyz="0 1 0" />
    <limit lower="-1.5707" upper="1.5707" effort="3" velocity="3" />
  </joint>
  <link name="pitch">
    <inertial>
      <origin xyz="-0.0116105304119787 -0.023613452107438 0.00616457125803832" rpy="0 0 0" />
      <mass value="0.0215001123670908" />
      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
    </inertial>
    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
  </link>
  <joint name="pitch" type="revolute">
    <origin xyz="0.00500000000000003 0.0226770569861576 0" rpy="2.47905368074654 -1.57079630572147 0.76162796200405" />
    <parent link="rolling" />
    <child link="pitch" />
    <axis xyz="1 0 0" />
    <limit lower="-1.5707" upper="1.5707" effort="3" velocity="3" />
  </joint>
  <link name="gripper">
    <inertial>
      <origin xyz="0.00568899451062876 0.000685064865752177 -0.00200000000000133" rpy="0 0 0" />
      <mass value="0.00259243385468487" />
      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
    </inertial>
    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
  </link>
  <joint name="gripper" type="revolute">
    <origin xyz="0.0039101 -0.037783 0.0145" rpy="3.1416 0 -1.0597" />
    <parent link="pitch" />
    <child link="gripper" />
    <axis xyz="0 0 1" />
    <limit lower="-1.5707" upper="1.5707" effort="3" velocity="3" />
  </joint>
  <link name="hand1">
    <inertial>
      <origin xyz="-0.0259511214514078 0.00395106521630019 0.00249999999999792" rpy="0 0 0" />
      <mass value="0.00304957364089639" />
      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
    </inertial>
    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
  </link>
  <joint name="hand1" type="fixed">
    <origin xyz="0.0305 0 0" rpy="0 0 -2.2812" />
    <parent link="gripper" />
    <child link="hand1" />
    <axis xyz="0 0 0" />
    <mimic joint="gripper" multiplier="1" offset="0" />
  </joint>
  <link name="follower-gear">
    <inertial>
      <origin xyz="0.00559728875614893 0.000674021719269072 0.00200000000000211" rpy="0 0 0" />
      <mass value="0.0026349081873614" />
      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
    </inertial>
    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
  </link>
  <joint name="follower-gear" type="revolute">
    <origin xyz="-0.023005 -0.037784 0.0145" rpy="0 0 -2.1964" />
    <parent link="pitch" />
    <child link="follower-gear" />
    <axis xyz="0 0 1" />
    <limit lower="-1.5707" upper="1.5707" effort="3" velocity="3" />
    <mimic joint="gripper" multiplier="1" offset="0" />
  </joint>
  <link name="hand2">
    <inertial>
      <origin xyz="-0.0259511214503139 0.00395106521859902 0.00250000000000208" rpy="0 0 0" />
      <mass value="0.00304957364089639" />
      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
    </inertial>
    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
  </link>
  <joint name="hand2" type="fixed">
    <origin xyz="0.0305 0 -0.005" rpy="0 0 -2.1872" />
    <parent link="follower-gear" />
    <child link="hand2" />
    <axis xyz="0 0 0" />
    <limit lower="-1.5707" upper="1.5707" effort="0" velocity="0" />
    <mimic joint="gripper" multiplier="-1" offset="0" />
  </joint>
  <link name="link1">
    <inertial>
      <origin xyz="0.0420511056348878 0.00437046116424403 -0.00699999999999787" rpy="0 0 0" />
      <mass value="0.000798763302631051" />
      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
    </inertial>
    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
  </link>
  <joint name="link1" type="fixed">
    <origin xyz="-0.023005 -0.037784 0.0145" rpy="0 0 -1.0009" />
    <parent link="pitch" />
    <child link="link1" />
    <axis xyz="0 0 0" />
    <limit lower="-1.5707" upper="1.5707" effort="3" velocity="3" />
    <mimic joint="gripper" multiplier="1" offset="0" />
  </joint>
  <link name="link2">
    <inertial>
      <origin xyz="0.0155 -1.38777878078145E-17 0.002" rpy="0 0 0" />
      <mass value="0.000798763302631051" />
      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
    </inertial>
    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
  </link>
  <joint name="link2" type="fixed">
    <origin xyz="-0.015 -0.057781 0.0055" rpy="0 0 -2.2374" />
    <parent link="pitch" />
    <child link="link2" />
    <axis xyz="0 0 0" />
    <limit lower="-1.5707" upper="1.5707" effort="3" velocity="3" />
    <mimic joint="gripper" multiplier="-1" offset="0" />
  </joint>
</robot>

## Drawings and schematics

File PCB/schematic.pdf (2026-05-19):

GND | GND VCC

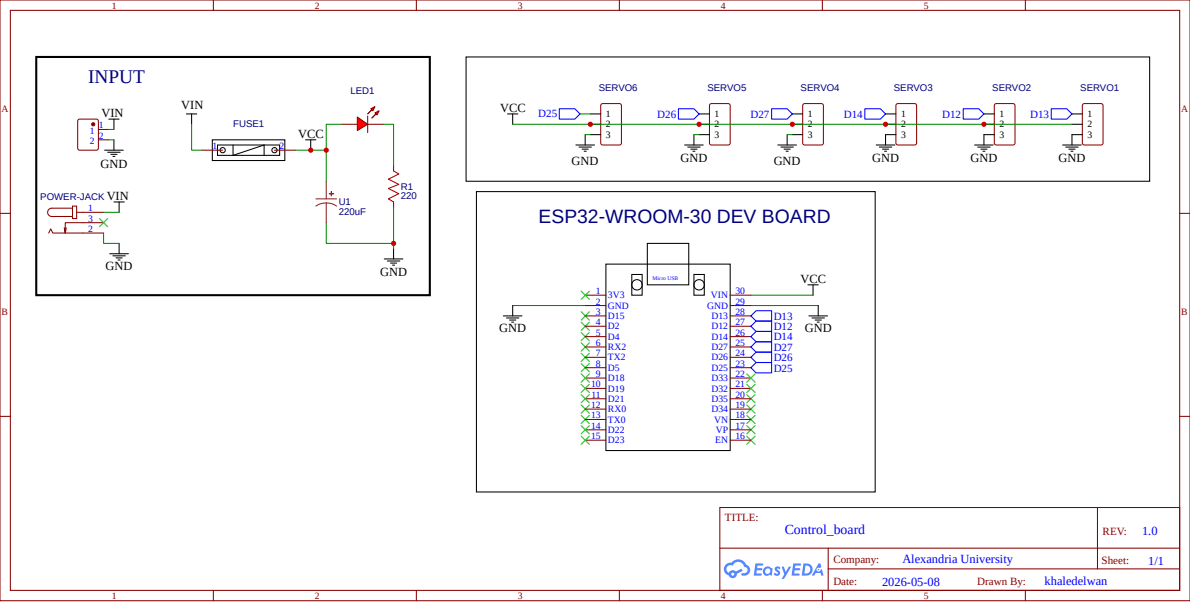
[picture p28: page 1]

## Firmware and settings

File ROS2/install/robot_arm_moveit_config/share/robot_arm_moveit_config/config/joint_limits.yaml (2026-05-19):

# joint_limits.yaml allows the dynamics properties specified in the URDF to be overwritten or augmented as need
# For beginners, we downscale velocity and acceleration limits.
# You can always specify higher scaling factors (<= 1.0) in your motion requests.  # Increase the values below to 1.0 to always move at maximum speed.
default_velocity_scaling_factor: 0.1
default_acceleration_scaling_factor: 0.1

# Specific joint properties can be changed with the keys [max_position, min_position, max_velocity, max_acceleration]
# Joint limits can be turned off with [has_velocity_limits, has_acceleration_limits]
joint_limits:
  shoulder:
    has_velocity_limits: true
    max_velocity: 3.0
    has_acceleration_limits: true
    max_acceleration: 0.5
  elbow:
    has_velocity_limits: true
    max_velocity: 3.0
    has_acceleration_limits: true
    max_acceleration: 0.5
  wrist:
    has_velocity_limits: true
    max_velocity: 3.0
    has_acceleration_limits: true
    max_acceleration: 0.5
  rolling:
    has_velocity_limits: true
    max_velocity: 3.0
    has_acceleration_limits: true
    max_acceleration: 0.5
  pitch:
    has_velocity_limits: true
    max_velocity: 3.0
    has_acceleration_limits: true
    max_acceleration: 0.5
  gripper:
    has_velocity_limits: true
    max_velocity: 3.0
    has_acceleration_limits: true
    max_acceleration: 0.5
  follower-gear:
    has_velocity_limits: true
    max_velocity: 3.0
    has_acceleration_limits: true
    max_acceleration: 0.5

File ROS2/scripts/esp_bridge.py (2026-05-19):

import rclpy
from rclpy.node import Node

from moveit_msgs.msg import DisplayTrajectory

import serial
import math
import time


class ESPBridge(Node):

    def __init__(self):

        super().__init__('esp_bridge')

        # ROS2 subscriber
        self.sub = self.create_subscription(
            DisplayTrajectory,
            '/display_planned_path',
            self.callback,
            10
        )

        # ESP serial
        self.ser = serial.Serial('/dev/ttyUSB1', 115200)

        print(" ESP Bridge Started")


    def rad_to_deg(self, rad):

        deg = (rad * 180.0 / math.pi)

        deg = deg + 90

        deg = max(0, min(180, deg))

        return int(deg)


    def callback(self, msg):

        if not msg.trajectory:
            return

        traj = msg.trajectory[0]

        names = traj.joint_trajectory.joint_names

        points = traj.joint_trajectory.points

        for p in points:

            joints = dict(zip(names, p.positions))

            shoulder = self.rad_to_deg(
                joints.get('shoulder', 0.0)
            )

            elbow = self.rad_to_deg(
                joints.get('elbow', 0.0)
            )

            wrist = self.rad_to_deg(
                joints.get('wrist', 0.0)
            )

            rolling = self.rad_to_deg(
                joints.get('rolling', 0.0)
            )

            pitch = self.rad_to_deg(
                joints.get('pitch', 0.0)
            )

            cmd = f"{shoulder},{elbow},{wrist},{rolling},{pitch}\n"

            self.ser.write(cmd.encode())

            print("Sent:", cmd.strip())

            time.sleep(0.05)


def main():

    rclpy.init()

    node = ESPBridge()

    rclpy.spin(node)

    rclpy.shutdown()


if __name__ == '__main__':
    main()

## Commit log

2026-05-12 moveit done
    [URDF.csv, URDF.ros2_control.xacro, URDF.urdf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]
2026-05-14 Done realtime simulation
    [URDF.ros2_control.xacro, URDF.urdf.xacro, joint_limits.yaml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]
2026-05-19 Add README
    Added comprehensive documentation for the 6-DOF robotic arm project, including project overview, repository structure, system specifications, and setup instructions.
2026-05-19 Update shoulder joint maximum limit to +90°

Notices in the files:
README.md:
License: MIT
